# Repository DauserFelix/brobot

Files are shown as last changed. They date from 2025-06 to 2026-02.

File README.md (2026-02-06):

# BroBot - 4-DOF Robot Arm with Cycloidal Gearbox

A DIY 4-axis robot arm driven by stepper motors with cycloidal reduction gears and inverse kinematics control.

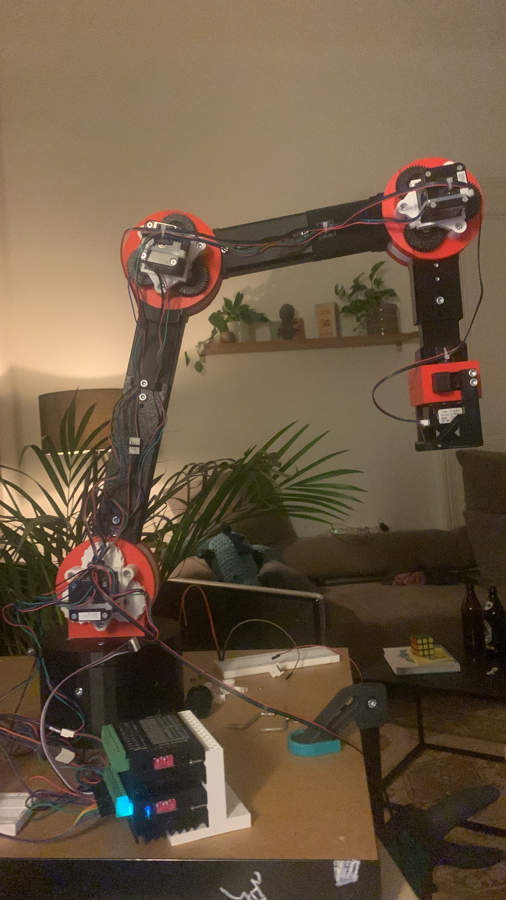
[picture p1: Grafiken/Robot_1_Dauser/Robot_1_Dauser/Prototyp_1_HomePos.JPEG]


BroBot is a DIY robot arm with 4 degrees of freedom (DOF) driven by stepper motors and cycloidal gearboxes. The project includes both the mechanical construction and software control with inverse kinematics for precise TCP positioning (Tool Center Point).

### Specifications

- **Degrees of Freedom:** 4 DOF
- **Base Height to Joint 1:** 150 mm
- **Link Lengths:**
  - L1: 150 mm (Base to Joint 1)
  - L2: 200 mm (Joint 1 to Joint 2)
  - L3: 180 mm (Joint 2 to Joint 3)
  - L4: 120 mm (Joint 3 to TCP)
- **Maximum Reach:** ~500 mm
- **Actuators:** NEMA 17/23 Stepper Motors
- **Gearing:** Cycloidal reduction gears (see exploded view)

## Features

### Hardware
- Cycloidal gearboxes for high reduction ratio and precision
- 3D printed components
- TB6600 stepper motor drivers (up to 4A)
- Arduino-based controller
- Compact design

### Software
- **Inverse Kinematics** - Control via cartesian coordinates (X, Y, Z)
- **Forward Kinematics** - Calculate TCP position from joint angles
- **Python Control Interface** - Command-line interface for easy operation
- **Arduino Firmware** - Real-time stepper motor control
- **Relative & Absolute Movement** - Flexible positioning options
- **Home Position** - Safe reference position

## Hardware

### Components

#### Drive System
- 4x NEMA 17/23 Stepper Motors
- 4x TB6600 Stepper Motor Drivers
- 1x Power Supply 24-36V DC (recommended)
- Arduino Uno/Mega

#### Mechanics
- Cycloidal gearboxes (3D printed)
- Structural parts (3D printed or aluminum)
- Various screws, bearings, and mounting hardware

### TB6600 Stepper Motor Driver

**Specifications:**
- Supply Voltage: 9-40 VDC (optimal: 24-36V)
- Output Current: 0.7-4.0A (adjustable via DIP switches)
- Microstepping Modes: up to 6400 steps/revolution
- Input Signal: 5V (optically isolated)
- Max. Pulse Frequency: 20 kHz

**Connections:**
- **PUL+/PUL-:** Pulse input (Step)
- **DIR+/DIR-:** Direction input
- **ENA+/ENA-:** Enable input
- **A+/A-, B+/B-:** Motor connections

**Important Notes:**
- For 12V control signals: add 1kΩ resistor in series
- For 24V control signals: add 2kΩ resistor in series

### Cycloidal Gearbox

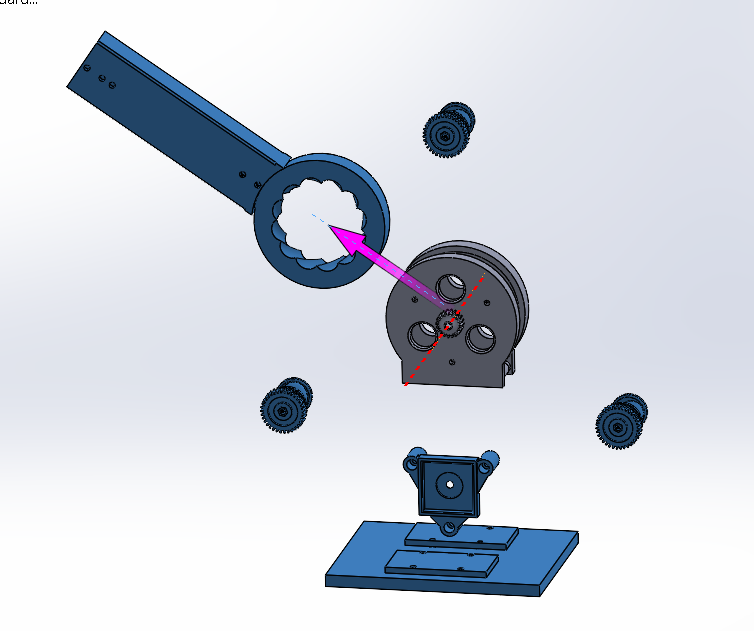
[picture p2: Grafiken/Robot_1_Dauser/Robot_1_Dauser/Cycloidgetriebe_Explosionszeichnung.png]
  

The cycloidal gearbox provides:
- High reduction ratios (typically 1:30 to 1:100)
- Very low backlash
- High stiffness
- Compact form factor
- Self-locking at high reduction ratios

## Software

### Architecture

```
┌─────────────────────────────────────┐
│   Python TCP Control Interface      │
│  (Inverse & Forward Kinematics)     │
└────────────────┬────────────────────┘
                 │ Serial (9600 baud)
                 │ Commands: J1:steps, J2:steps...
┌────────────────▼────────────────────┐
│     Arduino Firmware                │
│  (Stepper Control & Positioning)    │
└────────────────┬────────────────────┘
                 │ Step/Dir Signals
┌────────────────▼────────────────────┐
│      TB6600 Stepper Drivers         │
└────────────────┬────────────────────┘
                 │
┌────────────────▼────────────────────┐
│        Stepper Motors               │
└─────────────────────────────────────┘
```

### Calibration - Steps per Degree

The calibration values are based on measured data from the actual system:

| Joint | Steps/90° | Steps/Degree |
|---|---|---|
| 1 | 5500 | 61.11 |
| 2 | 8000 | 88.89 |
| 3 | 5000 | 55.56 |
| 4 | 5000 | 55.56 |

## Installation

### Prerequisites

- Python 3.7 or higher
- Arduino IDE
- pySerial library

### Python Setup

```bash
# Clone repository
git clone https://github.com/yourusername/brobot.git
cd brobot

# Create virtual environment (optional)
python -m venv venv
source venv/bin/activate  # Linux/Mac
# or
venv\Scripts\activate  # Windows

# Install dependencies
pip install pyserial
```

### Arduino Setup

1. Open Arduino IDE
2. Load `arudino_inverse_kinematics_automatic_ansteuerung_brobot.ino`
3. Select your board (Arduino Uno/Mega)
4. Select the correct COM port
5. Upload to Arduino

### Configuration

In `python_inverse_kinematics_brobot.py`:

```python
# Adjust serial port
arduino_port = 'COM3'  # Windows
# arduino_port = '/dev/ttyUSB0'  # Linux
# arduino_port = '/dev/tty.usbserial-XXX'  # Mac

# Link lengths (if different from default)
L1 = 150  # mm
L2 = 200  # mm
L3 = 180  # mm
L4 = 120  # mm
```

## Usage

### Starting the Control Interface

```bash
python python_inverse_kinematics_brobot.py
```

### Initialization

At startup, you'll be prompted to enter the current joint angles:

```
Please enter current joint angles (in degrees):
  Joint 1: 0
  Joint 2: 45
  Joint 3: 90
  Joint 4: -45
```

### Commands

#### Absolute Positioning
```bash
TCP> goto 300 100 200
# Moves TCP to position X=300mm, Y=100mm, Z=200mm
```

#### Relative Movement
```bash
TCP> up 10        # Move 10mm upward
TCP> down 5       # Move 5mm downward
TCP> forward 20   # Move 20mm forward
TCP> back 15      # Move 15mm backward
TCP> left 10      # Move 10mm to the left
TCP> right 10     # Move 10mm to the right
```

#### Other Commands
```bash
TCP> status       # Show current position and angles
TCP> home         # Move to home position
TCP> stop         # Stop all movements
TCP> help         # Show all commands
TCP> exit         # Exit program
```

### Example Session

```bash
TCP> goto 400 0 150
Moving TCP to position: X=400.0, Y=0.0, Z=150.0
Calculated joint angles:
  Joint 1: 0.0°
  Joint 2: 45.2°
  Joint 3: 67.8°
  Joint 4: -23.0°
→ Joint 1: 0.0° (0 Steps)
→ Joint 2: 45.2° (4018 Steps)
→ Joint 3: 67.8° (3767 Steps)
→ Joint 4: -23.0° (-1278 Steps)

TCP> up 50
[...]

TCP> status
============================================================
ROBOT STATUS
============================================================
TCP Position: X=400.0, Y=0.0, Z=200.0 mm

Joint Angles:
  Joint 1: 0.0°
  Joint 2: 52.3°
  Joint 3: 71.2°
  Joint 4: -33.5°
============================================================
```

## Kinematics

### Inverse Kinematics

The inverse kinematics algorithm calculates the required joint angles for a desired TCP position:

**Coordinate System:**
- X: Forward/Backward
- Y: Left/Right
- Z: Up/Down

**Solution Approach:**
1. Joint 1 (Base): `θ₁ = atan2(y, x)`
2. Reduce to 2D problem in the XZ plane
3. Calculate Joint 2 & 3 using the law of cosines
4. Joint 4: Compensate to keep end-effector horizontal

**Workspace Limits:**
- Maximum reach: L2 + L3 + L4 = 500 mm
- Minimum reach: |L2 - L3 - L4| (depends on configuration)

### Forward Kinematics

Calculates the TCP position from given joint angles:

```
x_tcp = (L2·cos(θ₂) + L3·cos(θ₂+θ₃) + L4·cos(θ₂+θ₃+θ₄)) · cos(θ₁)
y_tcp = (L2·cos(θ₂) + L3·cos(θ₂+θ₃) + L4·cos(θ₂+θ₃+θ₄)) · sin(θ₁)
z_tcp = L1 + L2·sin(θ₂) + L3·sin(θ₂+θ₃) + L4·sin(θ₂+θ₃+θ₄)
```

### Working Position
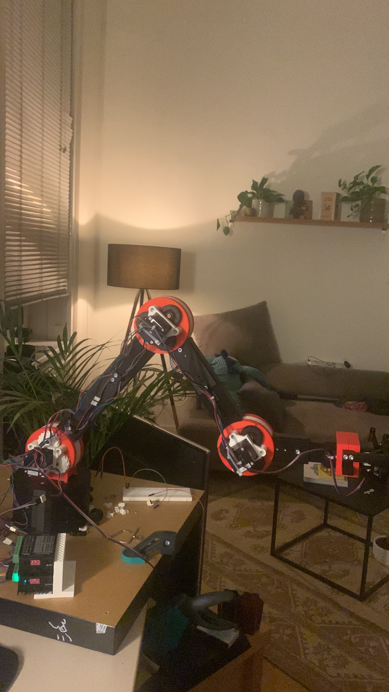
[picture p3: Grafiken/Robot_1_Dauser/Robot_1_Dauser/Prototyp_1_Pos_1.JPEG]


## End-Effector: Parallel Gripper with Toggle Mechanism

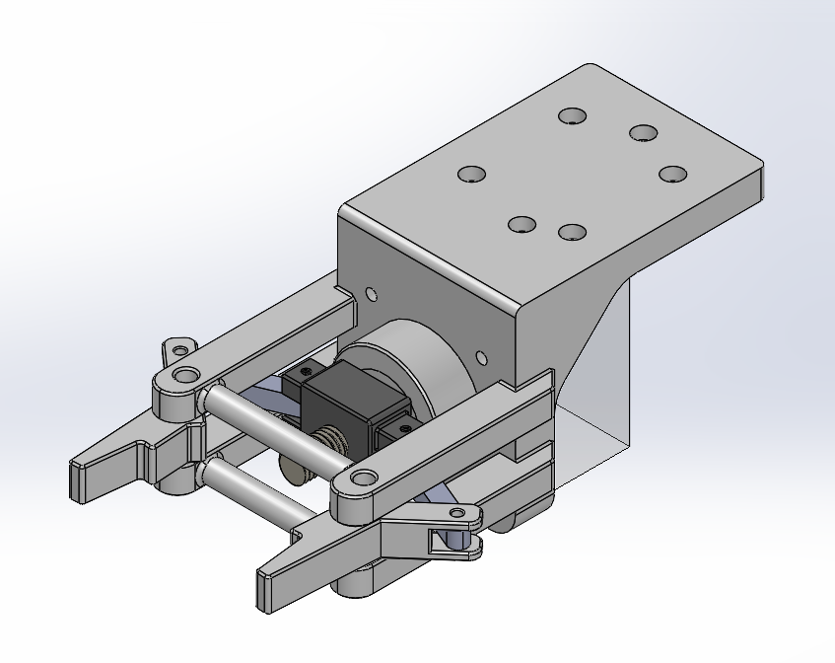
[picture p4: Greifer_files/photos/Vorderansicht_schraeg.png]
Gripper Perspective


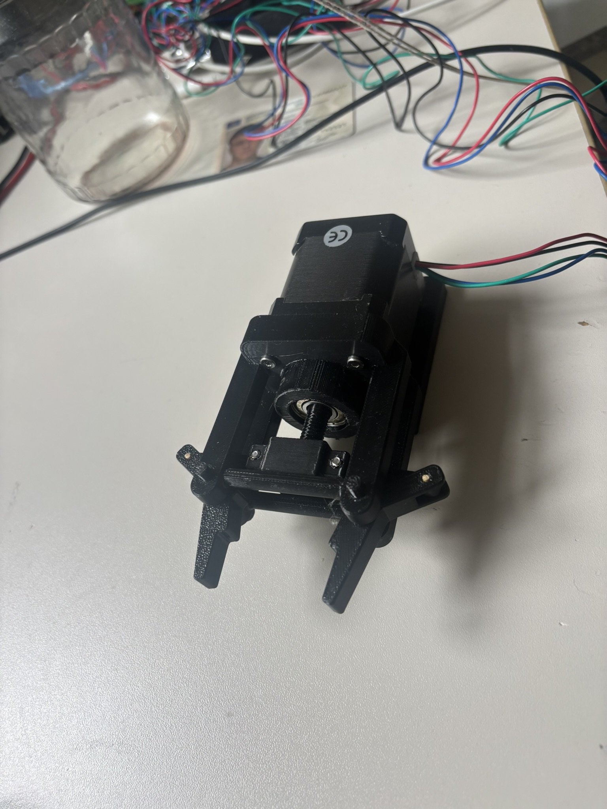
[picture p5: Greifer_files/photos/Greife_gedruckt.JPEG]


A motorized parallel gripper designed as an end-effector for the BroBot. The gripper uses a NEMA 17 stepper motor driven by the same TB6600 drivers as the robot joints.
Key Features

### Toggle Mechanism: Employs a knee-lever mechanism for mechanical advantage, dramatically amplifying gripping force as the jaws close
Same Hardware: Uses NEMA 17 motor and TB6600 driver (compatible with existing BroBot electronics)
Parallel Jaws: Ensures even pressure distribution across gripping surfaces
Compact Design: Lightweight and suitable for mounting on Joint 4/TCP

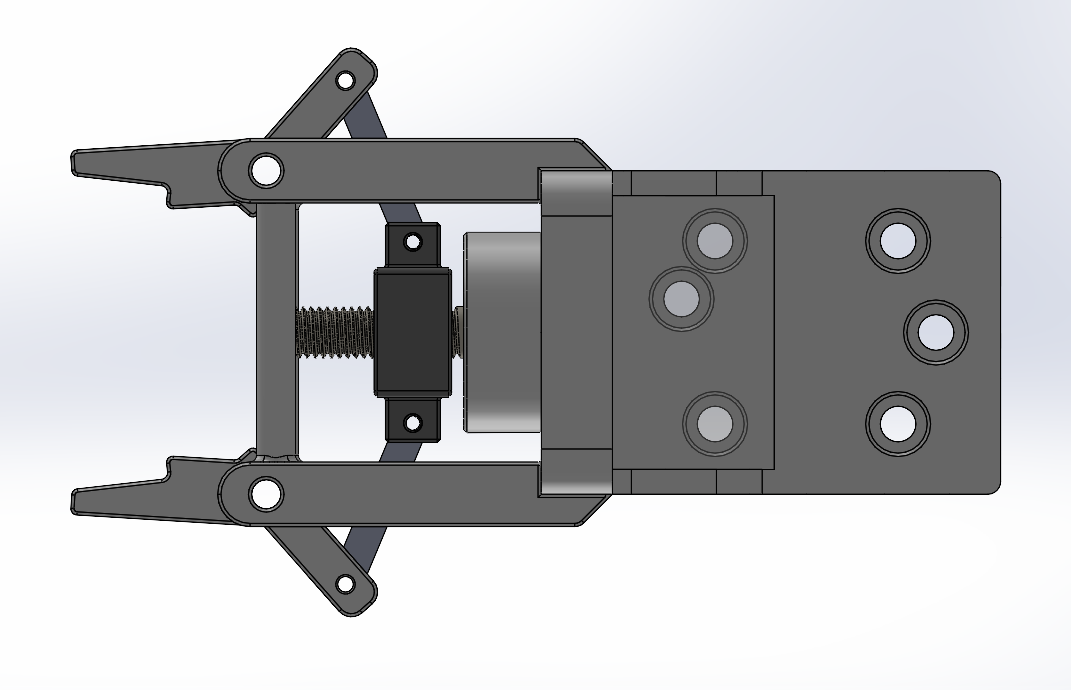
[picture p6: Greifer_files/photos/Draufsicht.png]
Gripper Top View


### Toggle Mechanism Principle
The gripper uses a toggle (knee-lever) mechanism that provides increasing mechanical advantage as the jaws approach the closed position. This allows high clamping forces with minimal motor torque and enables the gripper to maintain grip even when not actively powered.
Integration
The gripper connects mechanically to the BroBot's TCP and electrically to an additional TB6600 driver. Control is integrated into the existing Arduino/Python interface as an additional "Joint 5" for simple open/close commands.

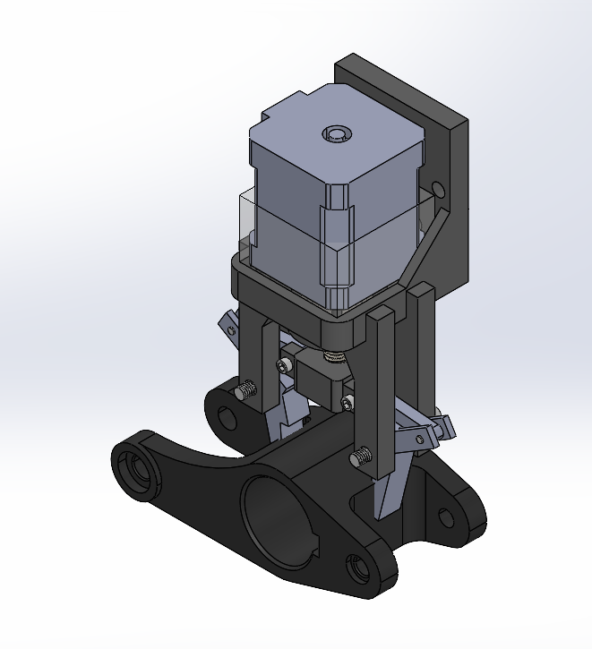
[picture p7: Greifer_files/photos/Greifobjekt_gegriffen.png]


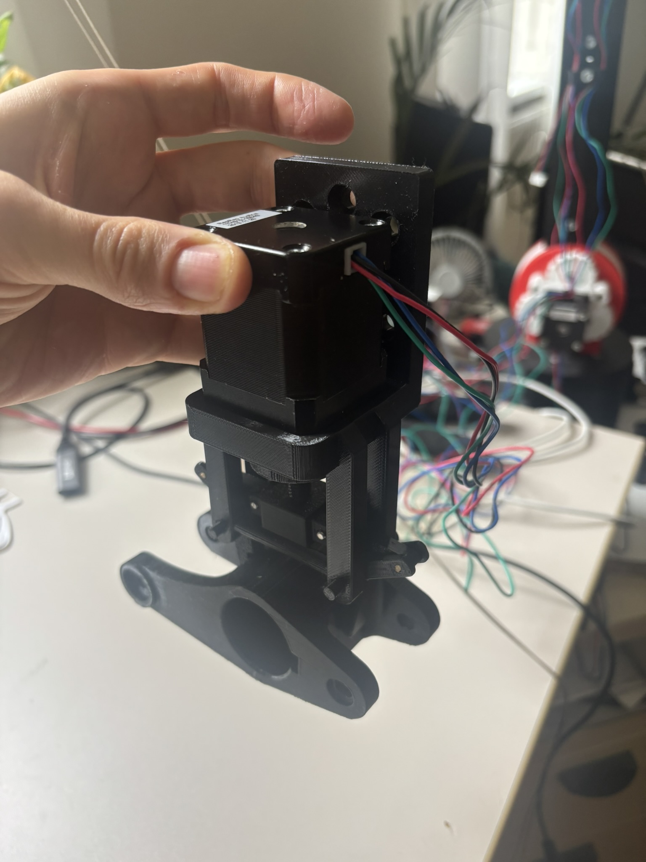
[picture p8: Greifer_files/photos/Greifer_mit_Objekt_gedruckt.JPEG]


### Components
1x NEMA 17 Stepper Motor
1x TB6600 Driver
3D printed gripper jaws and toggle linkages
Various bearings and fasteners

## Troubleshooting

### Common Issues

**Issue: "Position not reachable!"**
- Solution: Check if the target position is within the workspace
- Maximum reach: ~500mm from origin

**Issue: Motors not moving**
- Check wiring to TB6600 drivers
- Check power supply (minimum 9V)
- Check enable signal
- Verify DIP switch settings on TB6600

**Issue: Steps are being lost**
- Reduce speed (increase delay in Arduino code)
- Check current setting on TB6600
- Check for mechanical friction or binding

**Issue: Serial connection fails**
- Verify COM port in `python_inverse_kinematics_brobot.py`
- Check if Arduino is connected
- Close Arduino IDE Serial Monitor if open

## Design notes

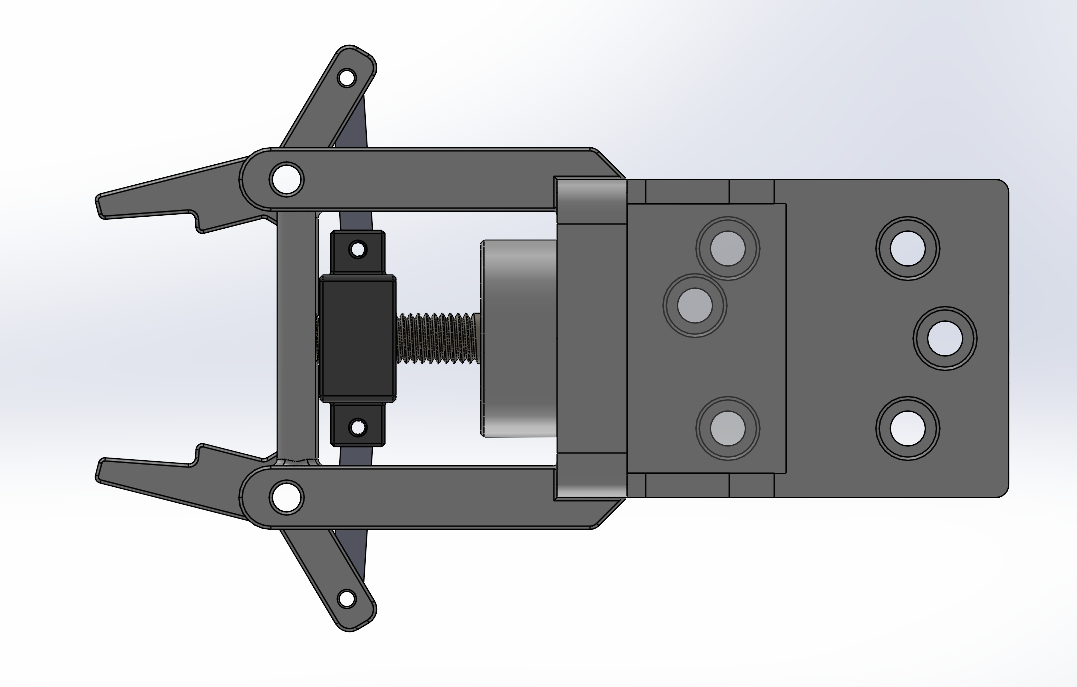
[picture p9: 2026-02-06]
Greifer_files/photos/Draufsicht_Greifer_geschlossen.png

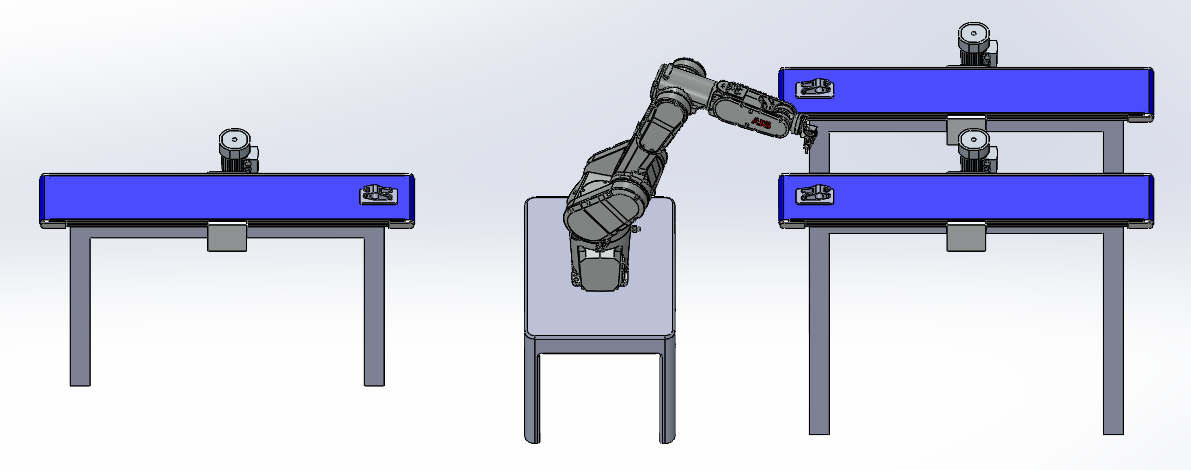
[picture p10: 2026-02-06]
Greifer_files/photos/Station_Seitenansicht_schraeg.png

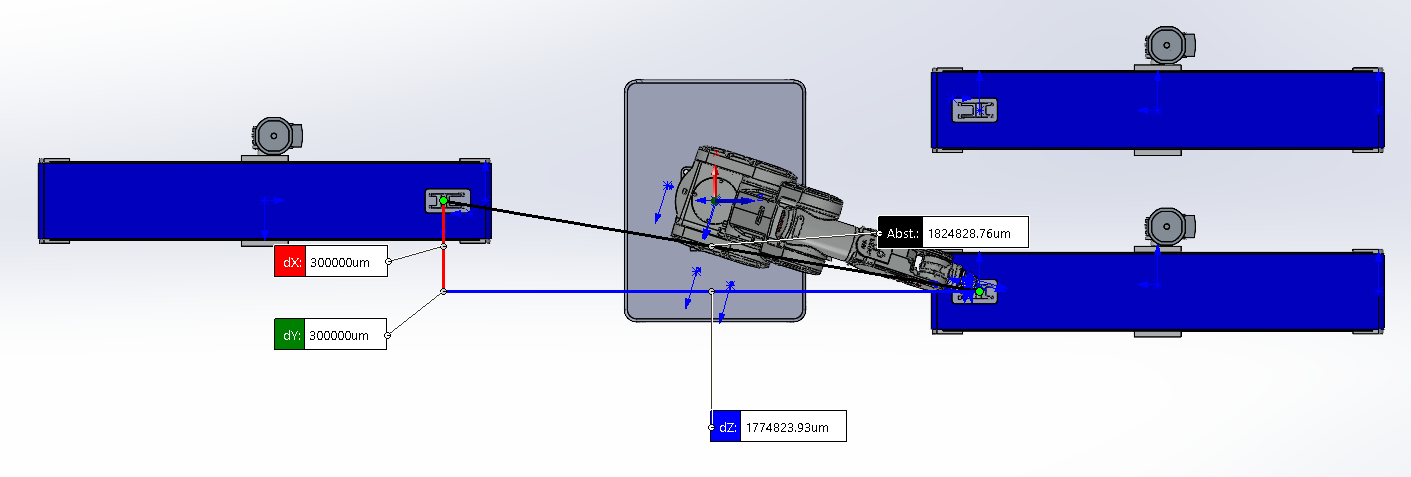
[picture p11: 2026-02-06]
Greifer_files/photos/Abstand_Aufnahme_und_Ablage_Draufsicht.png

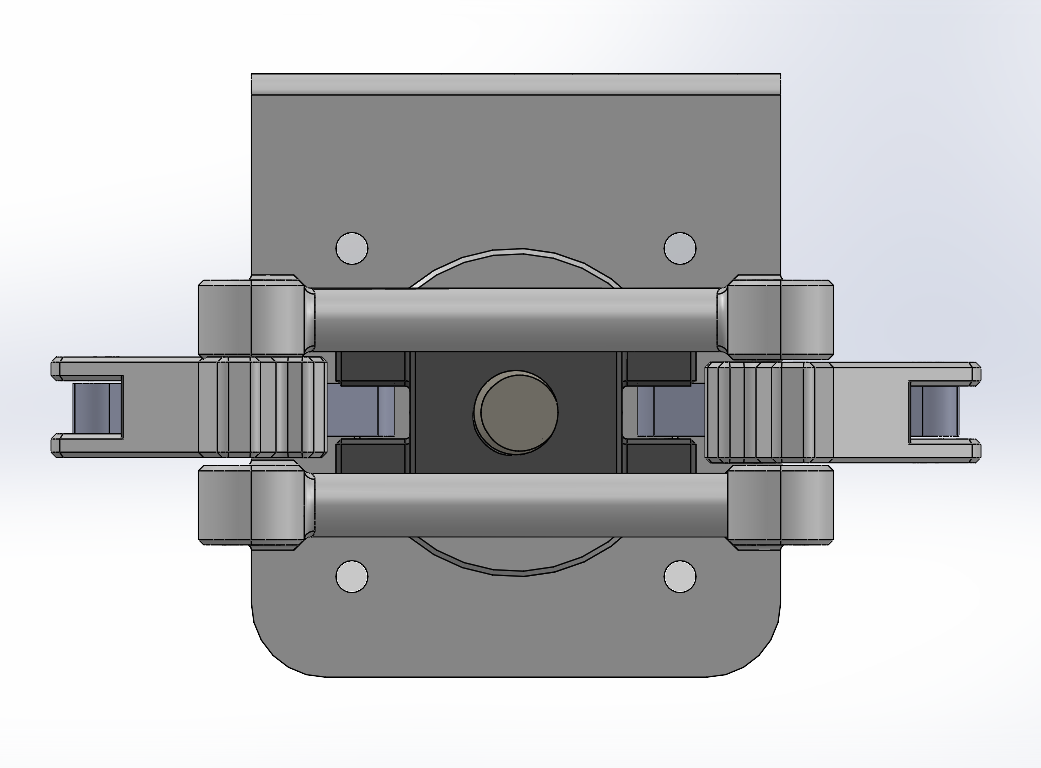
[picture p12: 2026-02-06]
Greifer_files/photos/Vorderansicht.png

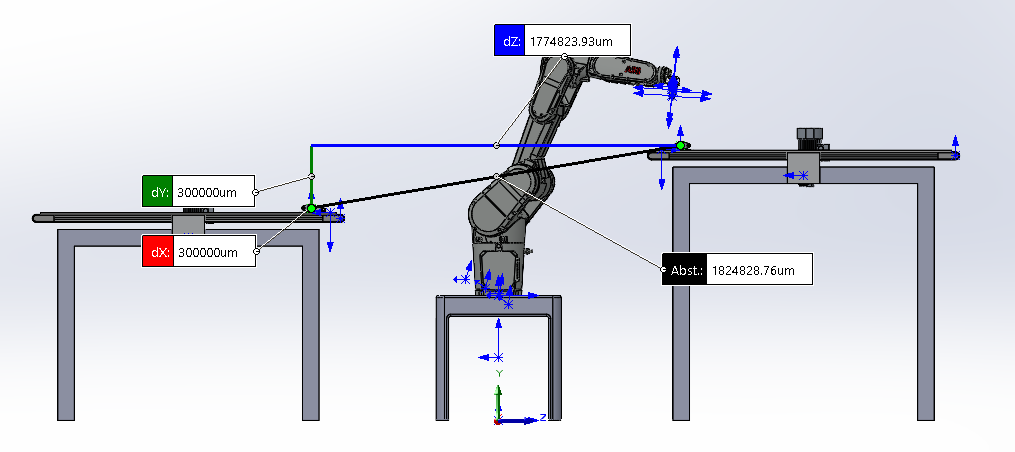
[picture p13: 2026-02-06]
Greifer_files/photos/Abstand_Aufnahme_und_Ablage_Seitenansicht.png

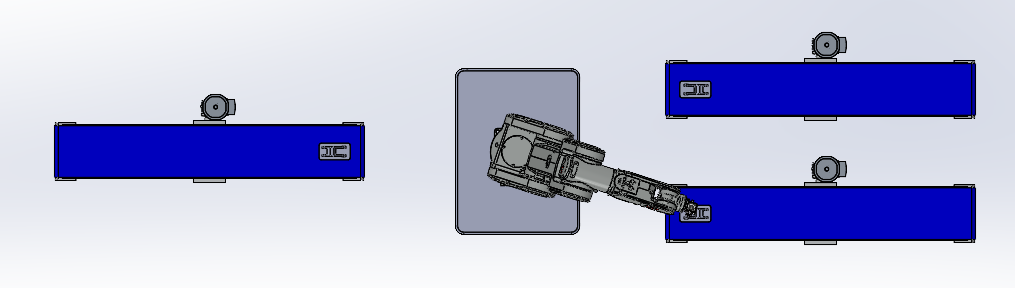
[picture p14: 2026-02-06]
Greifer_files/photos/Stattion_Draufsicht.png

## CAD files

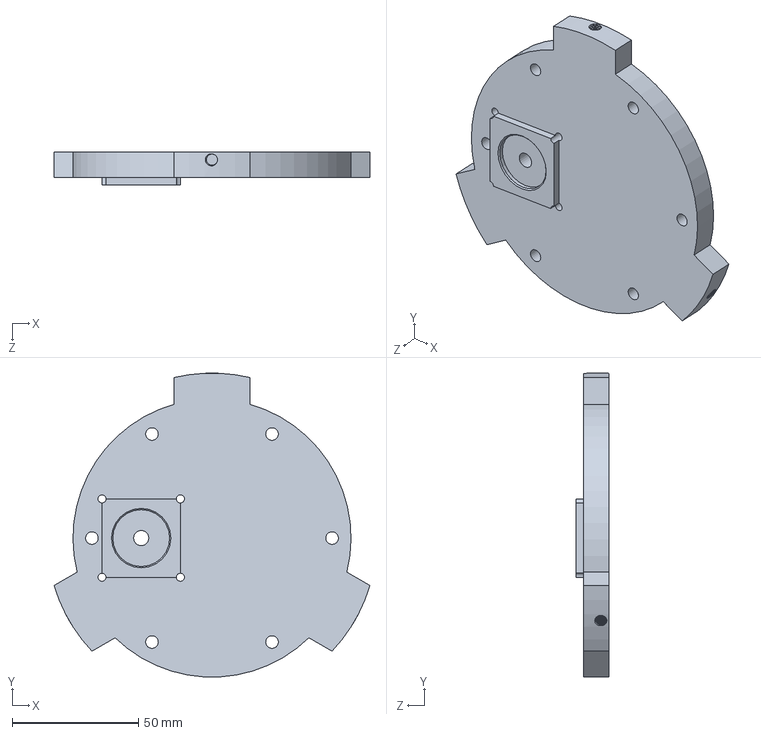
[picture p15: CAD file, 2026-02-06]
CAD/base/Base-Rotationsgelenk_4_v1.SLDPRT
125.0 x 120.2 x 13.0 mm

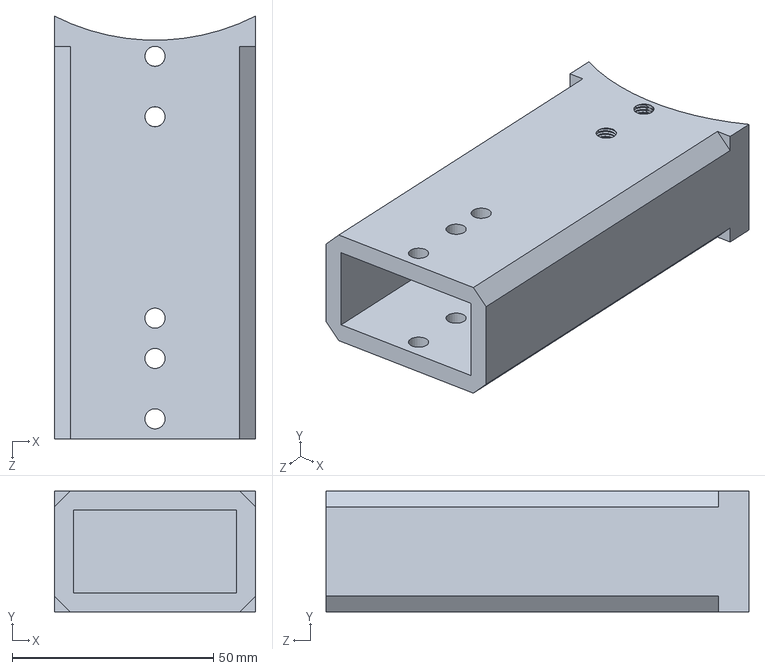
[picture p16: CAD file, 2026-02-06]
CAD/cycloid_innenkaefig/ausleger_3_100mm.SLDPRT
50.0 x 30.0 x 105.0 mm

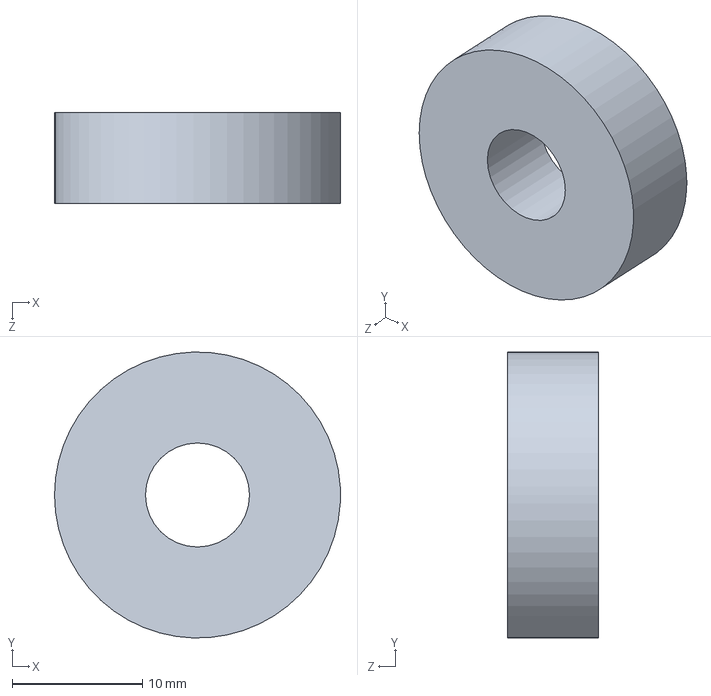
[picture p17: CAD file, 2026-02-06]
CAD/cycloid_innenkaefig/Joint_2_V3/Kugellager_22mm_8mm_7mm.SLDPRT
22.0 x 22.0 x 7.00 mm

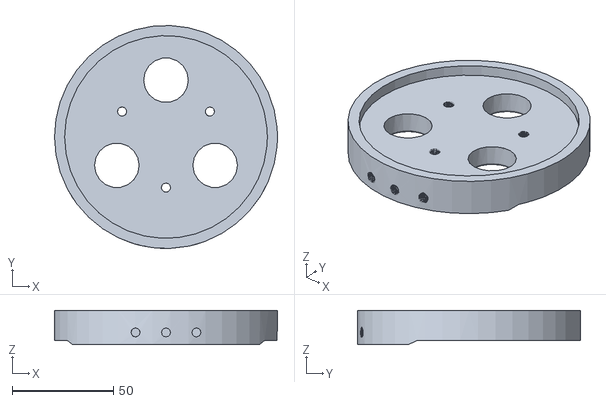
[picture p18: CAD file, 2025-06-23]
CAD/cycloid_innenkaefig/Joint_4/frame_3_v2_3_verstrebungen.STL
110.0 x 110.0 x 16.9

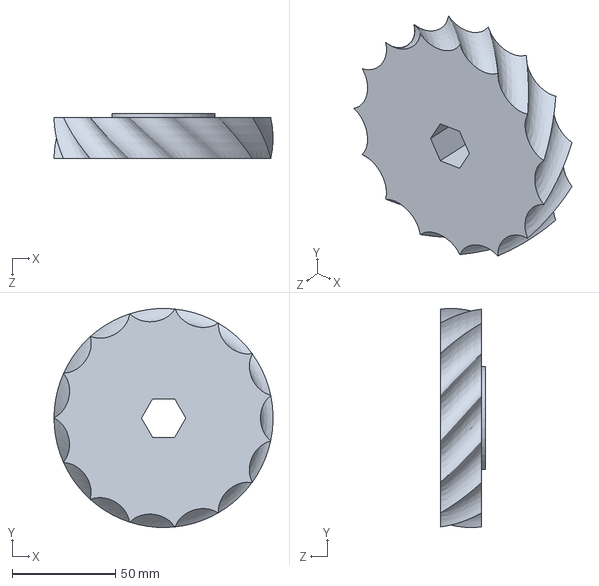
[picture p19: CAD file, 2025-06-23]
CAD/cycloid_innenkaefig/Voruebersetzung_cycloid_außen/Cycloidal_wheel.SLDPRT
106.1 x 106.1 x 22.0 mm

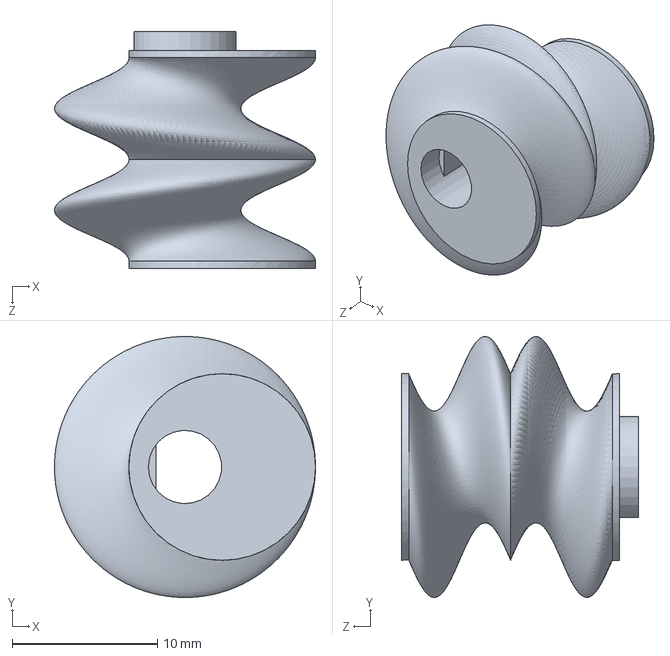
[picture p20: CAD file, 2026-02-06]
CAD/cycloid_innenkaefig/Voruebersetzung_cycloid_außen/V2.2/cycloid_welle.SLDPRT
18.0 x 18.0 x 16.3 mm

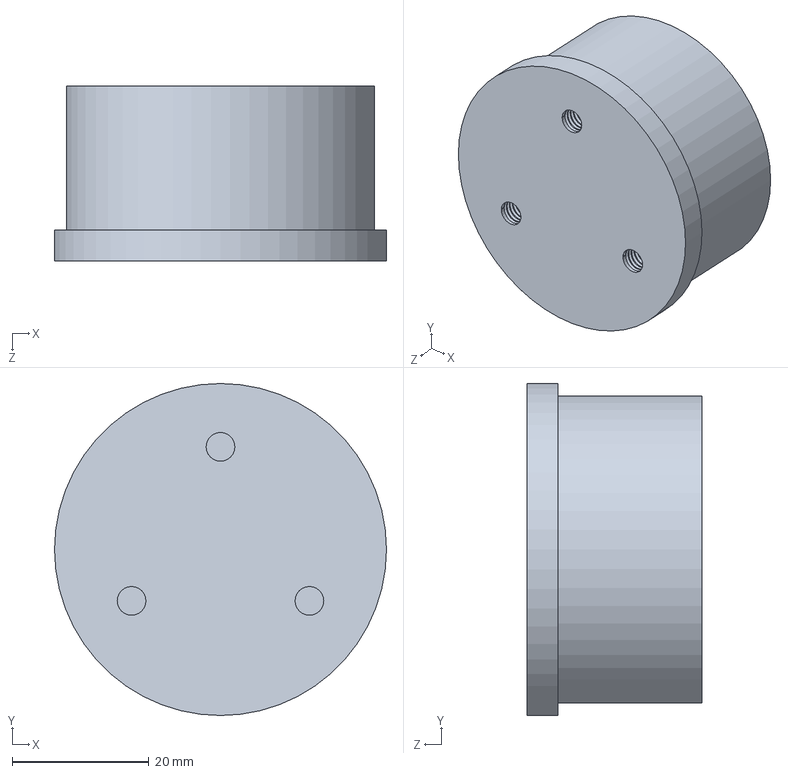
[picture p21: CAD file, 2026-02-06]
CAD/nylongetriebe/Version_1/Mittelachse.SLDPRT
48.5 x 48.5 x 25.5 mm

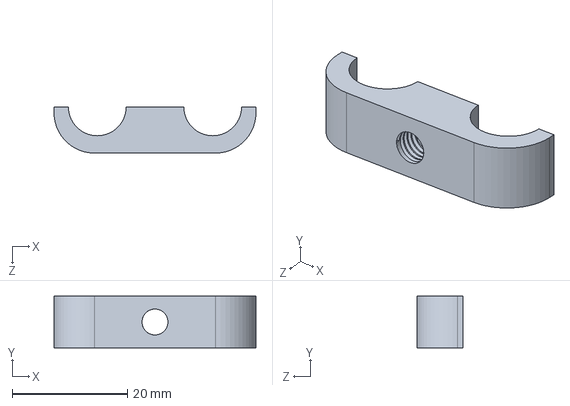
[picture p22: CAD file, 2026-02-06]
CAD/sonstiges/Kabelhalterung.SLDPRT
35.0 x 9.00 x 8.00 mm

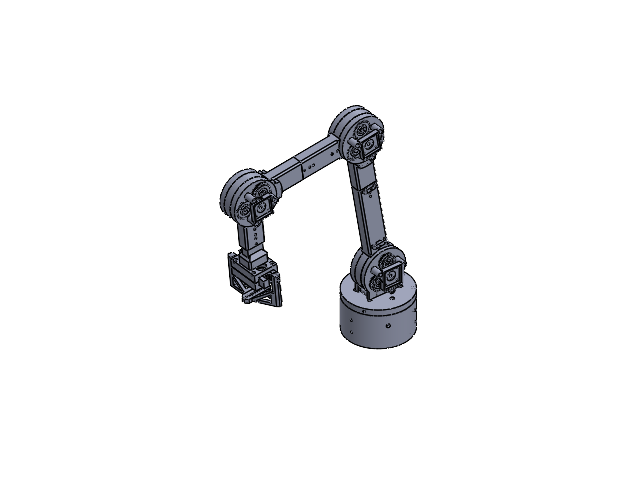
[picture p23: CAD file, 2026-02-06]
CAD/brobot.SLDASM
Base-Rotationsgelenk_3_v1
Base-Rotationsgelenk_2_v1
Base-Rotationsgelenk_1_v1
Base-Rotationsgelenk_4_v1
Cycloidal_pin_fuer_Base
Cycloidal_cage x 3
Teil4^Fully_cage
Cycloidal_pin_mit_fuehrung x 3
frame_2
frame_3
Zahnrad_1 x 3
Zahnrad_2_NEMA17
halterung_NEMA17 x 3
ausleger_1
frame_2_v2_3_Verstrebungen x 2
frame_3_v2_3_verstrebungen x 2
Cycloidal_pin_mit_fuehrung_und_Gewinde x 6
cycloid_rad x 6
cycloid_welle x 2
Kabelhalterung x 2
ausleger_3_100mm
ausleger_2_80mm x 2
frame_1_endeffektor
Linearführung_endeffektor_ x 2
Zahnrad_endeffektor
Zahnrad_endeffektor_fuehrung x 2
frame_2_endeffektor
gripper_1 x 2
ausleger_endeffektor
ausleger_endeffektor_verbindungselement
Greiferbacken x 2

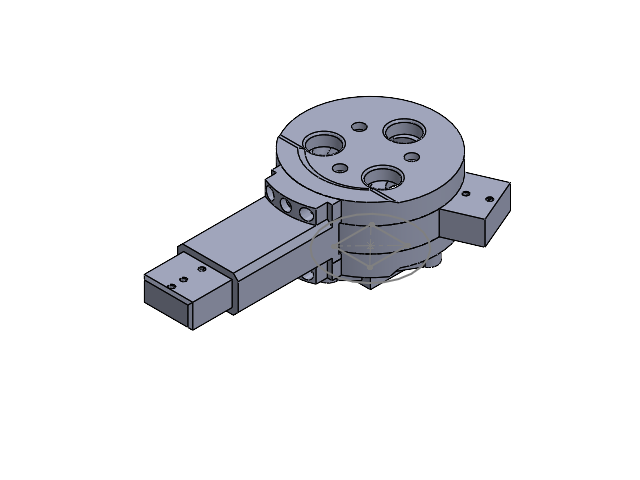
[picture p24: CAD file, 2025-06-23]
CAD/cycloid_innenkaefig/Joint_4/Joint_4.SLDASM
ausleger_2_80mm
frame_2_v2_3_Verstrebungen
frame_3_v2_3_verstrebungen
Cycloidal_cage
halterung_NEMA17

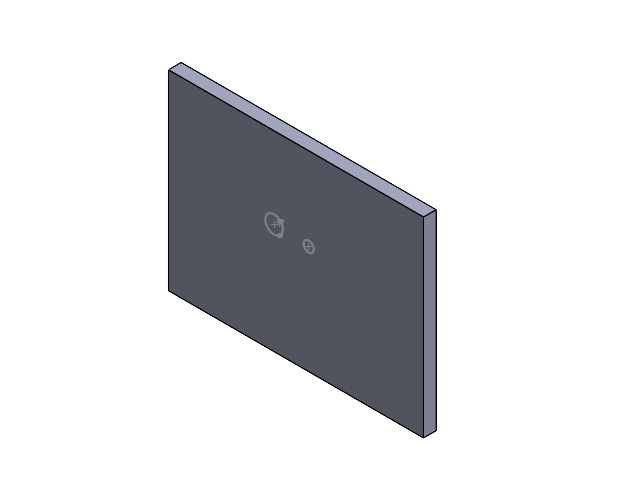
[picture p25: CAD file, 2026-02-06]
CAD/cycloid_innenkaefig/Voruebersetzung_cycloid_außen/V2.2/Cycloidgetriebe_own.SLDASM
Halterung_provisorisch
cycloid_rad
cycloid_welle

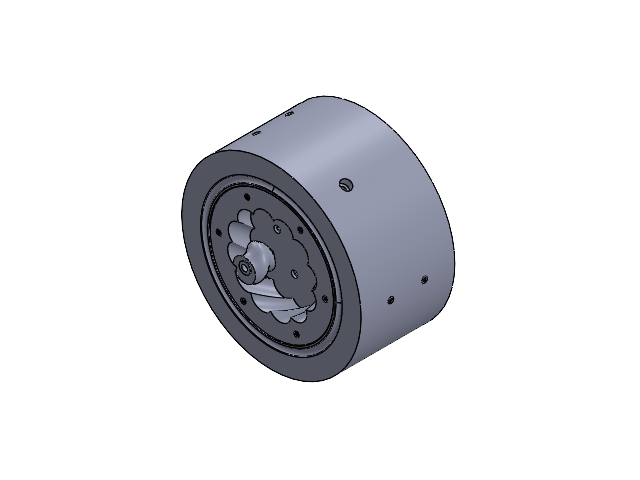
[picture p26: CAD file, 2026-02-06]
CAD/base/base.SLDASM
Base-Rotationsgelenk_2_v1
Base-Rotationsgelenk_1_v1
Base-Rotationsgelenk_4_v1
Cycloidal_pin_fuer_Base

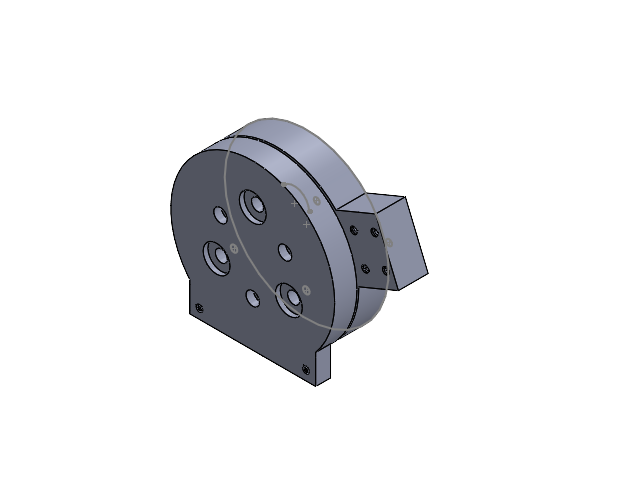
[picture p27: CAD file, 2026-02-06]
CAD/cycloid_innenkaefig/Joint_2_V3/Cycloidal_Joint_2.SLDASM
Kugellager_22mm_8mm_7mm x 5
Cycloidal_pin_mit_fuehrung_und_Gewinde x 2
frame_3
Cycloidal_cage

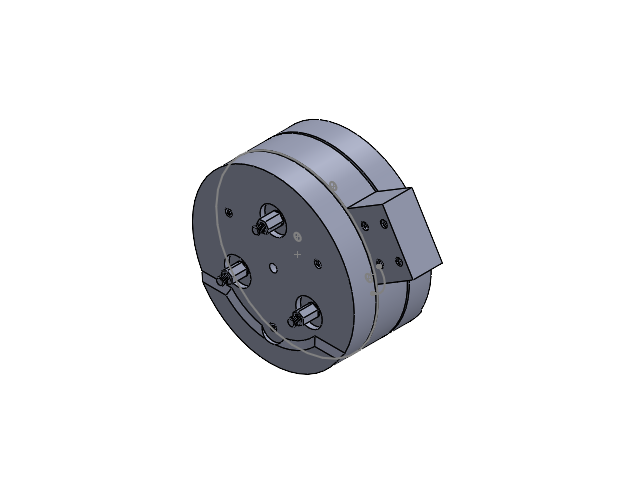
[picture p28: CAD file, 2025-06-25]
CAD/cycloid_innenkaefig/Joint_2_V3/Cycloidal_round.SLDASM
frame_3_v2_3_verstrebungen
Cycloidal_cage
Cycloidal_pin_mit_fuehrung_und_Gewinde x 3
frame_2_v2_3_Verstrebungen
Kugellager_22mm_8mm_7mm x 6

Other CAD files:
CAD/nylongetriebe/Version_1/System_1.SLDASM
CAD/cycloid_innenkaefig/Fully_cage_round.SLDASM
CAD/cycloid_innenkaefig/Fully_cage.SLDASM
CAD/cycloid_planetengetriebe/plaenen_cage.SLDPRT
CAD/base/Base-Rotationsgelenk_3_v1.STL
CAD/base/Base-Rotationsgelenk_4_v1.STL
CAD/base/Base-Rotationsgelenk_5_Sockel_v1.SLDPRT
CAD/base/Cycloidal_pin.SLDPRT
CAD/base/Cycloidal_pin_fuer_Base.SLDPRT
CAD/base/Cycloidal_pin_fuer_Base.STL
CAD/cycloid_innenkaefig/Cycloidal_cage.SLDPRT
CAD/cycloid_innenkaefig/Cycloidal_cage.STEP
CAD/cycloid_innenkaefig/Cycloidal_cage.STL
CAD/cycloid_innenkaefig/Cycloidal_pin.SLDPRT
CAD/cycloid_innenkaefig/Cycloidal_pin.STEP
CAD/cycloid_innenkaefig/Cycloidal_pin.STL
CAD/cycloid_innenkaefig/Cycloidal_pin_mit_fuehrung.SLDPRT
CAD/cycloid_innenkaefig/Cycloidal_pin_mit_fuehrung.STL
CAD/cycloid_innenkaefig/Cycloidal_pin_mit_fuehrung_und_Gewinde.SLDPRT
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

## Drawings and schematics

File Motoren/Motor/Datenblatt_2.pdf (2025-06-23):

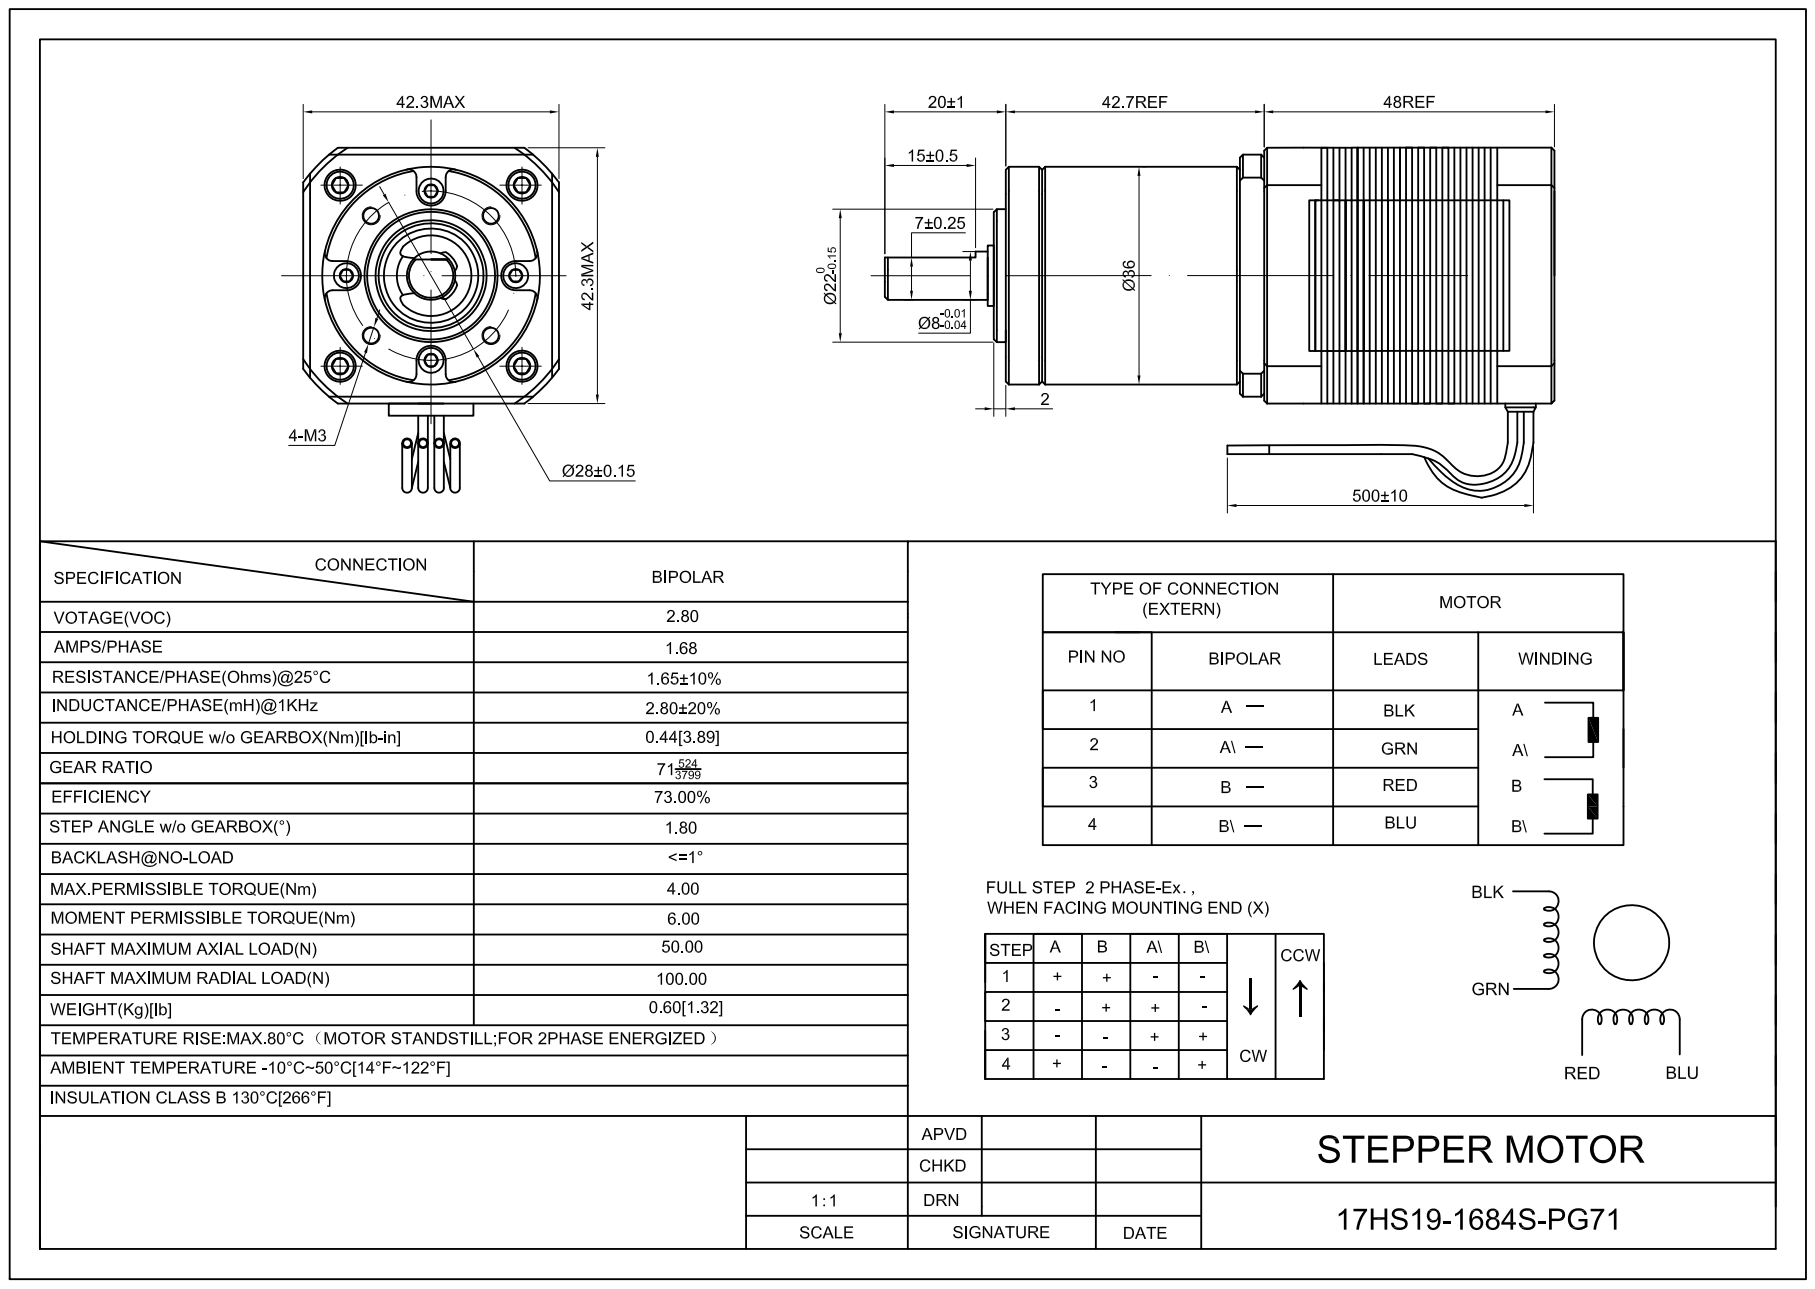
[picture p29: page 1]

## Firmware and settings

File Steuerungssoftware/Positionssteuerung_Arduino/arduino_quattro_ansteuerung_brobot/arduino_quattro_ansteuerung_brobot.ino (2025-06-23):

// TB6600 Schrittmotor-Treiber - Multi Joint Version (4 Joints)
const int JOINT1_PINS[3] = {8, 9, 10};   // STEP, DIR, ENA für Joint 1
const int JOINT2_PINS[3] = {11, 12, 13}; // STEP, DIR, ENA für Joint 2
const int JOINT3_PINS[3] = {5, 6, 7};    // STEP, DIR, ENA für Joint 3
const int JOINT4_PINS[3] = {2, 3, 4};    // STEP, DIR, ENA für Joint 4

// Aktuelle Pin-Variablen (werden je nach ausgewähltem Joint gesetzt)
int STEP_PIN = 8;
int DIR_PIN = 9;
int ENA_PIN = 10;

// Konfigurierbare Parameter
double pulseDelay = 400;     // Verzögerung zwischen Schritten in Mikrosekunden
boolean motorDirection = LOW;  // Drehrichtung (LOW oder HIGH)
boolean motorEnabled = true;   // Motor aktiviert (true) oder deaktiviert (false)
String receivedCommand = "";   // Empfangener Befehl
boolean commandComplete = false;

unsigned long lastStepTime = 0;
bool stepState = LOW;

// Fehlercodes - synchronisiert mit Python
const String CODE1 = "Code1: Position wurde angefahren";
const String CODE2 = "Code2: Vorgang wurde abgebrochen";
const String CODE3 = "Code3: Motor ist einsatzbereit!";
const String CODE4 = "Code4: Fehlerhafte Eingabe. Motor wurde abgeschaltet";

// Joint-Bestätigungscodes
const String JOINT1_CODE = "Arduino: Joint 1 wird angesteuert";
const String JOINT2_CODE = "Arduino: Joint 2 wird angesteuert";
const String JOINT3_CODE = "Arduino: Joint 3 wird angesteuert";
const String JOINT4_CODE = "Arduino: Joint 4 wird angesteuert";

// Positionsvariablen
long targetPosition = 0;
long currentPosition = 0;
boolean movingToPosition = false;

// Aktuell aktiver Joint
int currentJoint = 1;

// Debug-Variablen
unsigned long lastDebug = 0;
unsigned long stepCount = 0;

// Geschwindigkeitsstufen (1-5)
const double speedLevels[6] = {0, 1000, 600, 400, 200, 100}; // Index 0 unbenutzt, 1-5 für Stufen

void setup() {
  // Pin-Modi für alle vier Joints setzen
  for(int i = 0; i < 3; i++) {
    pinMode(JOINT1_PINS[i], OUTPUT);
    pinMode(JOINT2_PINS[i], OUTPUT);
    pinMode(JOINT3_PINS[i], OUTPUT);
    pinMode(JOINT4_PINS[i], OUTPUT);
  }
  
  // Serielle Kommunikation starten
  Serial.begin(9600);
  
  // Standardmäßig Joint 1 aktivieren
  setActiveJoint(1);
  
  // Anfangszustand setzen
  digitalWrite(DIR_PIN, motorDirection);
  digitalWrite(ENA_PIN, motorEnabled ? LOW : HIGH);  // LOW = aktiviert, HIGH = deaktiviert
  
  // Bereitschaftsmeldung
  Serial.println(CODE3);
  Serial.println("DEBUG: Setup abgeschlossen - Joint 1 aktiv");
  printStatus();
}

void loop() {
  // Auf serielle Befehle prüfen
  if (Serial.available() > 0) {
    char inChar = (char)Serial.read();
    
    // Spezielle Joint-Auswahl Befehle (als Byte-Werte)
    if (inChar == 1) {
      setActiveJoint(1);
      Serial.println(JOINT1_CODE);
      return;
    }
    else if (inChar == 2) {
      setActiveJoint(2);
      Serial.println(JOINT2_CODE);
      return;
    }
    else if (inChar == 3) {
      setActiveJoint(3);
      Serial.println(JOINT3_CODE);
      return;
    }
    else if (inChar == 4) {
      setActiveJoint(4);
      Serial.println(JOINT4_CODE);
      return;
    }
    
    // Normale String-Befehle verarbeiten
    if (inChar == '\n' || inChar == '\r') {
      if (receivedCommand.length() > 0) {
        commandComplete = true;
      }
    } else {
      receivedCommand += inChar;
    }
  }
  
  // Befehl verarbeiten
  if (commandComplete) {
    processCommand(receivedCommand);
    receivedCommand = "";
    commandComplete = false;
  }
  
  // Motor bewegen, wenn Zielposition gesetzt
  if (movingToPosition && motorEnabled) {
    moveToPosition();
  }
}

void setActiveJoint(int jointNumber) {
  currentJoint = jointNumber;
  
  if (jointNumber == 1) {
    STEP_PIN = JOINT1_PINS[0];
    DIR_PIN = JOINT1_PINS[1];
    ENA_PIN = JOINT1_PINS[2];
  } else if (jointNumber == 2) {
    STEP_PIN = JOINT2_PINS[0];
    DIR_PIN = JOINT2_PINS[1];
    ENA_PIN = JOINT2_PINS[2];
  } else if (jointNumber == 3) {
    STEP_PIN = JOINT3_PINS[0];
    DIR_PIN = JOINT3_PINS[1];
    ENA_PIN = JOINT3_PINS[2];
  } else if (jointNumber == 4) {
    STEP_PIN = JOINT4_PINS[0];
    DIR_PIN = JOINT4_PINS[1];
    ENA_PIN = JOINT4_PINS[2];
  }
  
  // Bewegung stoppen beim Joint-Wechsel
  movingToPosition = false;
  currentPosition = 0;
  targetPosition = 0;
  
  // Motor-Zustand für neuen Joint setzen
  digitalWrite(DIR_PIN, motorDirection);
  digitalWrite(ENA_PIN, motorEnabled ? LOW : HIGH);
  
  Serial.print("DEBUG: Joint ");
  Serial.print(jointNumber);
  Serial.println(" ist jetzt aktiv");
}

void printStatus() {
  Serial.println("=== STATUS ===");
  Serial.print("Aktiver Joint: ");
  Serial.print(currentJoint);
  Serial.print(" | Position: ");
  Serial.print(currentPosition);
  Serial.print(" | Ziel: ");
  Serial.print(targetPosition);
  Serial.print(" | Bewegung: ");
  Serial.print(movingToPosition ? "JA" : "NEIN");
  Serial.print(" | Motor: ");
  Serial.print(motorEnabled ? "EIN" : "AUS");
  Serial.print(" | Delay: ");
  Serial.print(pulseDelay);
  Serial.print("µs | Steps: ");
  Serial.println(stepCount);
  Serial.println("==============");
}

void processCommand(String command) {
  command.trim();
  
  Serial.print("DEBUG: Befehl empfangen: '");
  Serial.print(command);
  Serial.println("'");
  
  if (command.equalsIgnoreCase("Stop")) {
    Serial.println("DEBUG: Stop-Befehl");
    movingToPosition = false;
    targetPosition = currentPosition;
    Serial.println(CODE2);
  }
  else if (command.equalsIgnoreCase("Go")) {
    Serial.println("DEBUG: Go-Befehl");
    motorEnabled = true;
    digitalWrite(ENA_PIN, LOW);
    Serial.println(CODE3);
  }
  else if (command == "test") {
    Serial.println("DEBUG: Test-Bewegung gestartet");
    targetPosition = currentPosition + 200;  // 200 Steps vorwärts
    movingToPosition = true;
    motorDirection = HIGH;
    digitalWrite(DIR_PIN, motorDirection);
    Serial.println("Test durchgeführt!"); // Bestätigung
  }
  // Geschwindigkeitsstufen s1-s5
  else if (command == "s1" || command == "s2" || command == "s3" || command == "s4" || command == "s5") {
    int speedLevel = command.substring(1).toInt(); // "s1" -> 1
    pulseDelay = speedLevels[speedLevel];
    Serial.print("Geschwindigkeitsstufe ");
    Serial.print(speedLevel);
    Serial.print(" gesetzt (");
    Serial.print(pulseDelay);
    Serial.println("µs)");
  }
  else if (command.equalsIgnoreCase("d")) {
    Serial.println("DEBUG: Richtungswechsel");
    motorDirection = !motorDirection;  // Richtung umkehren
    digitalWrite(DIR_PIN, motorDirection);
    Serial.println("Richtung geändert"); // Bestätigung
  }
  else if (command.equalsIgnoreCase("e")) {
    Serial.println("DEBUG: Motor ein/aus");
    motorEnabled = !motorEnabled;
    digitalWrite(ENA_PIN, motorEnabled ? LOW : HIGH);  // LOW = aktiviert
    Serial.println("Motor " + String(motorEnabled ? "EIN" : "AUS")); // Bestätigung
  }
  else if (command.equals("+")) {
    Serial.println("DEBUG: Geschwindigkeit erhöhen");
    pulseDelay = max(pulseDelay - 200, 100);  // Mindestverzögerung 100µs
    Serial.print("Geschwindigkeit erhöht auf ");
    Serial.print(pulseDelay);
    Serial.println("µs");
  }
  else if (command.equals("-")) {
    Serial.println("DEBUG: Geschwindigkeit verringern");
    pulseDelay += 200;  // Verzögerung erhöhen
    Serial.print("Geschwindigkeit verringert auf ");
    Serial.print(pulseDelay);
    Serial.println("µs");
  }
  else if (command.equalsIgnoreCase("status")) {
    printStatus();
  }
  else if (command.equalsIgnoreCase("h")) {
    Serial.println("=== HILFE ===");
    Serial.println("s1-s5: Geschwindigkeitsstufen");
    Serial.println("d: Richtung wechseln");
    Serial.println("e: Motor ein/aus");
    Serial.println("+: Geschwindigkeit erhöhen");
    Serial.println("-: Geschwindigkeit verringern");
    Serial.println("Stop: Bewegung stoppen");
    Serial.println("Go: Motor aktivieren");
    Serial.println("status: Status anzeigen");
    Serial.println("Zahl: Position anfahren");
    Serial.println("==============");
  }
  else {
    // Versuche als Zahl zu interpretieren (Positionsbefehl)
    long position = command.toInt();
    
    if (position != 0 || command == "0") {
      // Berechne die Richtung anhand der Differenz
      long delta = position - currentPosition;
      motorDirection = (delta > 0) ? HIGH : LOW;
      digitalWrite(DIR_PIN, motorDirection);
      
      targetPosition = position;
      movingToPosition = true;
      
      Serial.print("DEBUG: Zielposition: ");
      Serial.print(targetPosition);
      Serial.print(" | Delta: ");
      Serial.println(delta);
    } else {
      Serial.println("DEBUG: Ungültige Eingabe");
      motorEnabled = false;
      digitalWrite(ENA_PIN, HIGH);
      movingToPosition = false;
      Serial.println(CODE4);
    }
  }
}

void moveToPosition() {
  if (currentPosition != targetPosition) {
    if (micros() - lastStepTime >= pulseDelay) {
      stepState = !stepState;
      digitalWrite(STEP_PIN, stepState);
      
      if (stepState == LOW) {
        // Positionsupdate mit Richtungsüberprüfung
        if (motorDirection == HIGH) {
          currentPosition++;
        } else {
          currentPosition--;
        }
        stepCount++;
      }
      lastStepTime = micros();
    }
  } else {
    movingToPosition = false;
    Serial.println(CODE1);  // Bestätigung senden
  }
}

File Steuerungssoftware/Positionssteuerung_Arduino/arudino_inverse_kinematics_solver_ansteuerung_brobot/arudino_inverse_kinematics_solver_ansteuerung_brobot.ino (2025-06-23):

// TB6600 Multi-Joint Stepper Control für TCP Steuerung
const int JOINT1_PINS[3] = {8, 9, 10};   // STEP, DIR, ENA für Joint 1 (Base)
const int JOINT2_PINS[3] = {11, 12, 13}; // STEP, DIR, ENA für Joint 2 (Shoulder)
const int JOINT3_PINS[3] = {5, 6, 7};    // STEP, DIR, ENA für Joint 3 (Elbow)
const int JOINT4_PINS[3] = {2, 3, 4};    // STEP, DIR, ENA für Joint 4 (Wrist)

// Motor-Parameter für jeden Joint
struct JointMotor {
  int stepPin;
  int dirPin;
  int enaPin;
  long targetPosition;
  long currentPosition;
  bool moving;
  bool direction;
  unsigned long lastStepTime;
  double pulseDelay;
  bool stepState;
};

// Joint-Motoren initialisieren
JointMotor joints[4] = {
  {8, 9, 10, 0, 0, false, false, 0, 400, false},   // Joint 1
  {11, 12, 13, 0, 0, false, false, 0, 400, false}, // Joint 2
  {5, 6, 7, 0, 0, false, false, 0, 400, false},    // Joint 3
  {2, 3, 4, 0, 0, false, false, 0, 400, false}     // Joint 4
};

// Globale Parameter
double globalSpeed = 400;  // Standard Geschwindigkeit in µs
String receivedCommand = "";
boolean commandComplete = false;
boolean allMotorsEnabled = true;
int activeMotors = 0;

// Status-Codes
const String CODE1 = "Code1: Position wurde angefahren";
const String CODE2 = "Code2: Vorgang wurde abgebrochen";
const String CODE3 = "Code3: Motor ist einsatzbereit!";
const String CODE4 = "Code4: Fehlerhafte Eingabe. Motor wurde abgeschaltet";

void setup() {
  Serial.begin(9600);
  
  // Initialisiere alle Joint-Pins
  for(int i = 0; i < 4; i++) {
    pinMode(joints[i].stepPin, OUTPUT);
    pinMode(joints[i].dirPin, OUTPUT);
    pinMode(joints[i].enaPin, OUTPUT);
    
    // Motoren aktivieren (LOW = aktiv)
    digitalWrite(joints[i].enaPin, LOW);
    digitalWrite(joints[i].dirPin, LOW);
    digitalWrite(joints[i].stepPin, LOW);
    
    joints[i].pulseDelay = globalSpeed;
  }
  
  Serial.println("DEBUG: 4-Joint TCP Control bereit");
  Serial.println(CODE3);
  printStatus();
}

void loop() {
  // Serielle Kommunikation verarbeiten
  if (Serial.available() > 0) {
    char inChar = (char)Serial.read();
    
    if (inChar == '\n' || inChar == '\r') {
      if (receivedCommand.length() > 0) {
        commandComplete = true;
      }
    } else {
      receivedCommand += inChar;
    }
  }
  
  // Befehl verarbeiten
  if (commandComplete) {
    processCommand(receivedCommand);
    receivedCommand = "";
    commandComplete = false;
  }
  
  // Alle Motoren bewegen
  moveAllMotors();
  
  // Prüfe ob alle Motoren ihre Ziele erreicht haben
  checkMovementComplete();
}

void processCommand(String command) {
  command.trim();
  
  Serial.print("DEBUG: Befehl empfangen: '");
  Serial.print(command);
  Serial.println("'");
  
  if (command.equalsIgnoreCase("STOP")) {
    Serial.println("DEBUG: STOP - Alle Motoren stoppen");
    stopAllMotors();
    Serial.println(CODE2);
  }
  else if (command.equalsIgnoreCase("GO")) {
    Serial.println("DEBUG: GO - Alle Motoren aktivieren");
    enableAllMotors();
    Serial.println(CODE3);
  }
  else if (command.equalsIgnoreCase("status")) {
    printStatus();
  }
  else if (command.startsWith("SPEED:")) {
    // Globale Geschwindigkeit setzen: SPEED:300
    double newSpeed = command.substring(6).toDouble();
    if (newSpeed >= 100 && newSpeed <= 2000) {
      globalSpeed = newSpeed;
      for(int i = 0; i < 4; i++) {
        joints[i].pulseDelay = globalSpeed;
      }
      Serial.print("Geschwindigkeit gesetzt auf ");
      Serial.print(globalSpeed);
      Serial.println("µs");
    } else {
      Serial.println("Ungültige Geschwindigkeit (100-2000µs)");
    }
  }
  else if (command.startsWith("J") && command.indexOf(":") > 0) {
    // Joint-Befehl: J1:1000, J2:-500, etc.
    int colonPos = command.indexOf(":");
    int jointNum = command.substring(1, colonPos).toInt();
    long targetSteps = command.substring(colonPos + 1).toInt();
    
    if (jointNum >= 1 && jointNum <= 4) {
      setJointTarget(jointNum - 1, targetSteps);  // Array ist 0-basiert
    } else {
      Serial.println("Ungültige Joint-Nummer (1-4)");
      Serial.println(CODE4);
    }
  }
  else if (command.startsWith("MULTI:")) {
    // Multi-Joint Befehl: MULTI:J1:1000,J2:-500,J3:200,J4:0
    parseMultiJointCommand(command.substring(6));
  }
  else {
    Serial.println("DEBUG: Unbekannter Befehl");
    Serial.println(CODE4);
  }
}

void parseMultiJointCommand(String jointCommands) {
  Serial.println("DEBUG: Multi-Joint Befehl wird verarbeitet");
  
  // Teile die Befehle bei Kommas
  int startPos = 0;
  int commaPos = 0;
  
  while (commaPos >= 0) {
    commaPos = jointCommands.indexOf(',', startPos);
    String singleCommand;
    
    if (commaPos >= 0) {
      singleCommand = jointCommands.substring(startPos, commaPos);
      startPos = commaPos + 1;
    } else {
      singleCommand = jointCommands.substring(startPos);
    }
    
    singleCommand.trim();
    
    // Verarbeite einzelnen Joint-Befehl
    if (singleCommand.startsWith("J") && singleCommand.indexOf(":") > 0) {
      int colonPos = singleCommand.indexOf(":");
      int jointNum = singleCommand.substring(1, colonPos).toInt();
      long targetSteps = singleCommand.substring(colonPos + 1).toInt();
      
      if (jointNum >= 1 && jointNum <= 4) {
        setJointTarget(jointNum - 1, targetSteps);
      }
    }
  }
}

void setJointTarget(int jointIndex, long targetSteps) {
  if (jointIndex < 0 || jointIndex >= 4) return;
  
  joints[jointIndex].targetPosition = targetSteps;
  
  // Berechne Richtung
  long delta = targetSteps - joints[jointIndex].currentPosition;
  joints[jointIndex].direction = (delta > 0);
  digitalWrite(joints[jointIndex].dirPin, joints[jointIndex].direction ? HIGH : LOW);
  
  // Starte Bewegung wenn Unterschied vorhanden
  if (delta != 0) {
    joints[jointIndex].moving = true;
    activeMotors++;
  }
  
  Serial.print("Joint ");
  Serial.print(jointIndex + 1);
  Serial.print(" Ziel: ");
  Serial.print(targetSteps);
  Serial.print(" (Delta: ");
  Serial.print(delta);
  Serial.println(")");
}

void moveAllMotors() {
  for (int i = 0; i < 4; i++) {
    if (joints[i].moving && allMotorsEnabled) {
      moveJoint(i);
    }
  }
}

void moveJoint(int jointIndex) {
  if (jointIndex < 0 || jointIndex >= 4) return;
  
  JointMotor* joint = &joints[jointIndex];
  
  if (joint->currentPosition != joint->targetPosition) {
    if (micros() - joint->lastStepTime >= joint->pulseDelay) {
      joint->stepState = !joint->stepState;
      digitalWrite(joint->stepPin, joint->stepState);
      
      if (joint->stepState == LOW) {
        // Position aktualisieren
        if (joint->direction) {
          joint->currentPosition++;
        } else {
          joint->currentPosition--;
        }
      }
      joint->lastStepTime = micros();
    }
  } else {
    // Ziel erreicht
    if (joint->moving) {
      joint->moving = false;
      activeMotors--;
      Serial.print("Joint ");
      Serial.print(jointIndex + 1);
      Serial.println(" Ziel erreicht");
    }
  }
}
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

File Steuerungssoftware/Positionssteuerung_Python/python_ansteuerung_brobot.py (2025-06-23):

import serial
import time
import threading
import queue

# Fehlercodes - synchronisiert mit Arduino
Fehlercode1 = "Code1: Position wurde angefahren"
Fehlercode2 = "Code2: Vorgang wurde abgebrochen"
Fehlercode3 = "Code3: Motor ist einsatzbereit!"
Fehlercode4 = "Code4: Fehlerhafte Eingabe. Motor wurde abgeschaltet"

# Message Queue für Thread-sichere Kommunikation
message_queue = queue.Queue()
running = True

# Serielle Verbindungsparameter
arduino_port = 'COM3'  # Passe den Port an
baud_rate = 9600

# Verbindung zur seriellen Schnittstelle herstellen
ser = serial.Serial(arduino_port, baud_rate, timeout=1)
time.sleep(2)  # Arduino Zeit zum Initialisieren geben

def send_data(data):
    """Daten an Arduino senden."""
    ser.flushInput()   # Eingangspuffer leeren
    ser.flushOutput()  # Ausgangspuffer leeren
    ser.write((str(data) + '\n').encode())
    print(f"→ Befehl gesendet: {data}")

def read_data():
    """Daten vom Arduino empfangen."""
    if ser.in_waiting > 0:
        received_data = ser.readline().decode().strip()
        return received_data
    return None

def continuous_read():
    """Kontinuierliches Lesen von Arduino-Nachrichten."""
    global running
    while running:
        try:
            message = read_data()
            if message:
                message_queue.put(message)
            time.sleep(0.01)
        except Exception as e:
            print(f"Fehler beim Lesen: {e}")
            break

def clear_buffers():
    """Alle seriellen Puffer leeren."""
    ser.flushInput()
    ser.flushOutput()
    time.sleep(0.1)
    while ser.in_waiting > 0:
        ser.read()
    # Queue auch leeren
    while not message_queue.empty():
        try:
            message_queue.get_nowait()
        except queue.Empty:
            break
    #print("Puffer geleert")

def main():
    """Hauptprogramm - Einfache Positionssteuerung."""
    print("=" * 50)
    print("• Position         → Fahre zu Position")
    print("• Stop             → Bewegung stoppen") 
    print("• Go               → Motor aktivieren")
    print("=" * 50)
    
    # Puffer initial leeren
    clear_buffers()
    
    while True:
        try:
            user_input = input("\nPosition eingeben: ").strip()
            
            if user_input.lower() == 'exit':
                print("Programm wird beendet...")
                break
            elif user_input.lower() == 'clear':
                clear_buffers()
                continue
            
            # Befehl senden
            send_data(user_input)
            
            # Auf Antwort warten
            print("Warte auf Arduino-Antwort...")
            timeout_start = time.time()
            response_received = False
            
            while not response_received and (time.time() - timeout_start) < 15:
                try:
                    message = message_queue.get(timeout=0.5)
                    
                    # Prüfe auf spezielle Fehlercodes
                    if message == Fehlercode1:
                        print(f" {message}")
                        response_received = True
                    elif message == Fehlercode2:
                        print(f" {message}")
                        response_received = True
                    elif message == Fehlercode3:
                        print(f" {message}")
                        response_received = True
                    elif message == Fehlercode4:
                        print(f" {message}")
                        print("Motor mit 'Go' aktivieren!")
                        response_received = True
                    else:
                        # Normale Arduino-Nachricht
                        print(f" Arduino: {message}")
                        # Bei normalen Nachrichten nicht als "response_received" markieren
                        # außer es ist offensichtlich eine Bestätigung
                        if any(keyword in message.lower() for keyword in ['gesetzt', 'geändert', 'aktiviert', 'deaktiviert', 'durchgeführt']):
                            response_received = True
                
                except queue.Empty:
                    # Kein Timeout-Fehler, einfach weiter warten
                    continue
            
            if not response_received:
                print(" Timeout - Arduino antwortet nicht!")
                print(" Versuche 'clear' oder 'Stop'")
    
        except KeyboardInterrupt:
            print("\n Programm unterbrochen!")
            send_data("Stop")
            break
        except Exception as e:
            print(f" Fehler: {e}")

# Programm starten
try:
    # Starte kontinuierliches Lesen in separatem Thread
    read_thread = threading.Thread(target=continuous_read, daemon=True)
    read_thread.start()
    
    # Hauptprogramm starten
    main()
    
except KeyboardInterrupt:
    print("\n Programm wird beendet...")
    send_data("Stop")
finally:
    running = False
    ser.close()
    print("Verbindung geschlossen")

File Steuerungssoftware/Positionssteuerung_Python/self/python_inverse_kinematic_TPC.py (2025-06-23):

import serial
import time
import math


def send_data(data):
    ser.write((str(data) + '\n').encode())

def read_data():
    received_data = ser.readline().decode().strip()
    return received_data

def print_from_py(x):
    print("Python-> " +x)

def print_from_ardu(x):
    print("Arduino-> "+x)

def inverse_kinematik(old_x, old_y, old_thetta, new_x, new_y, new_thetta):
    print_from_py("Starte berechnung der Inversen Kinematik")

    l1=154      #mm
    l2=368
    l3=289
    l4=260

    x_1=0
    y_1=0
    x_2=0
    y_2=l1

    #Berechnung TCP zu Joint 4 (OLD)
    x_tcp_old=old_x
    y_tcp_old=old_y

    x_4_old=x_tcp_old-math.sin(math.radians(old_thetta))*l4
    y_4_old=y_tcp_old+math.cos(math.radians(old_thetta))*l4

    #x_4_old=old_x
    #y_4_old=old_y

    #Berechnung Joint4 zu Joint 2 (OLD)
    l24_old=math.sqrt(math.pow((x_4_old-x_2),2)+math.pow((y_4_old-y_2),2))
    alpha_groß_old=math.atan2(x_4_old,(y_4_old-y_2))         #für acos eher atan2 nehmen, dann auch negative werte
    alpha_old=math.acos(((-1)*math.pow(l3,2)+math.pow(l2,2)+math.pow(l24_old,2))/(2*l2*l24_old))
    alpha_2_old=alpha_groß_old-alpha_old

    y_3_old=y_2+math.cos(alpha_2_old)*l2
    x_3_old=x_2+math.sin(180-90-alpha_2_old)*l2

    beta_old=math.acos(((-1)*math.pow(l24_old,2)+math.pow(l3,2)+math.pow(l2,2))/(2*l3*l2))
    gamma_old=math.acos(((-1)*math.pow(l2,2)+math.pow(l3,2)+math.pow(l24_old,2))/(2*l3*l24_old))

    #epsilon_old=math.atan2(x_4_old,y_4_old)
    epsilon_old=math.asin(x_4_old/l24_old)

    thetta_gamma_old=(math.pi/2)-epsilon_old-gamma_old

    thetta_epsilon_old=math.radians(old_thetta)+epsilon_old+gamma_old

    if(x_4_old<x_1):
        epsilon_old=math.pi-epsilon_old

    #Berechnung TCP zu Joint 4 (OLD)
    x_tcp_new=new_x
    y_tcp_new=new_y

    x_4_new=x_tcp_new-math.sin(math.radians(new_thetta))*l4
    y_4_new=y_tcp_new+math.cos(math.radians(new_thetta))*l4

    #x_4_new=new_x
    #y_4_new=new_y

    #Berechnung Joint4 zu Joint 2
    l24_new=math.sqrt(math.pow((x_4_new-x_2),2)+math.pow((y_4_new-y_2),2))
    alpha_groß_new=math.atan2(x_4_new,(y_4_new-y_2))
    alpha_new=math.acos(((-1)*math.pow(l3,2)+math.pow(l2,2)+math.pow(l24_new,2))/(2*l2*l24_new))
    alpha_2_new=alpha_groß_new-alpha_new

    y_3_new=y_2+math.cos(alpha_2_new)*l2
    x_3_new=x_2+math.sin(180-90-alpha_2_new)*l2

    beta_new=math.acos(((-1)*math.pow(l24_new,2)+math.pow(l3,2)+math.pow(l2,2))/(2*l3*l2))
    gamma_new=math.acos(((-1)*math.pow(l2,2)+math.pow(l3,2)+math.pow(l24_new,2))/(2*l3*l24_new))

    #epsilon_new=math.atan2(x_4_new,y_4_new)
    epsilon_new=math.asin(x_4_new/l24_new)
    
    if(x_4_new<x_1):
        epsilon_new=math.pi-epsilon_new

    

    thetta_gamma_new=(math.pi/2)-epsilon_new-gamma_new

    thetta_epsilon_new=math.radians(new_thetta)+epsilon_new+gamma_new

    #Berechnung der Differenz
    delta_alpha=alpha_2_old-alpha_2_new     #weil Winkel nicht im Dreieck sondern auserhalb (daher old-new)
    delta_beta=beta_new-beta_old

    delta_epsilon_thetta=thetta_epsilon_new-thetta_epsilon_old

    #delta_thetta_2=math.radians(new_thetta)-math.radians(old_thetta)
    delta_thetta_gamma=math.radians(thetta_gamma_old)-math.radians(thetta_gamma_new)
    

    #joint 2: 32800 Stepps für 360°
    alpha_stepps=(32800/(2*math.pi))*(delta_alpha)        #stepps die der motor jetzt machen muss, um auf die Position zu fahren

    #joint 3:25200 Stepps für 360°
    beta_stepps=(25200/(2*math.pi))*(delta_beta)

    #joint 4: 13000 Stepps für 360°
    thetta_stepps=(13000/(2*math.pi))*(delta_epsilon_thetta)
    #thetta_stepps=(13000/(2*math.pi))*(delta_thetta_gamma)

    print_from_py("Berechnung beendet, alpha um "+str(math.degrees(delta_alpha)) +"° verfahren und beta um "+str(math.degrees(delta_beta)) +"° verfahren und epsilon "+str(math.degrees(delta_epsilon_thetta)) +"° verfahren!")
    return alpha_stepps, beta_stepps, thetta_stepps

    #Hier jetzt noch relative Bewegung zur alten tcp_x und tcp_y berechnen
    #Programmieren, dass:
    # 1. Bei der Initialisierung die X und Y Koordinaten der Aktuellen Position eingegeben werden müssen
    # 2. alte Position gespeichert wird
    # 3. Die Neue Position anhand der Alten angefahren wird
    # 4. Messen, wie Viele schritte pro Gelenk eine Umdrehung sind 
    #       [Joint 1 (rotation): 5500Stepps := 90°]" [Joint 2: 8200Stepps := 90°]" Joint 3:[6300Stepps := 90°]" Joint 4:[3250Stepps := 90°]"
    #  5. Arduino gleichzeiteige Bewegung: alle Stepps gleich schnell, nur Schritte der Motoren übergeben (Taktung gleich bzw in
    #  einer Funktion!)


    #   6. Berechnen TCP zu Joint4 : 
    #   7. Quadrantenprüfung (wann + und wann -) zu joint 4 und TCP
    #   8. programmieren dass alle gleichzeitig fahren
    #   9. eventuell threatten (skripte gleichzeitig ablaufen lassen)

    #Differenz der aktuellen


   

    

    print_from_py("Inverse Kinematik berechnet")


# Serielle Verbindungsparameter
arduino_port = 'COM3'  # Portangabe Windows
#arduino_port = '/dev/ttyUSB0'  # Portangabe Linux
baud_rate = 9600

# Verbindung zur seriellen Schnittstelle herstellen
ser = serial.Serial(arduino_port, baud_rate, timeout=5)
time.sleep(2)  # Arduino Zeit zum Initialisieren geben

#main
print('----Brobot-Controll----\n Modus Wählen (automatic "a" or manuell "m") ')
inputdata=input()
send_data(inputdata)

data=""
stepindex=0
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

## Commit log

2025-06-23 Innitial commit
    [17HS19-2004S1.STEP, Abrollrad.SLDPRT, Abrollscheibe.SLDPRT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]
2026-02-06 All relevant files for the project
    [Abrollrad.SLDPRT, Abrollrad.STL, Base-Halterungen_Aufrecht.SLDPRT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]
2026-02-06 added gripper files
2026-02-06 Add README for BroBot project
    Added comprehensive README for BroBot project, detailing features, hardware, software, installation, usage, kinematics, troubleshooting, and contributions.
2026-02-06 Update image path for BroBot prototype in README
2026-02-06 Fix image path in README.md
    Updated image path for the BroBot prototype.
2026-02-06 Fix image path in README.md
    Updated image path for BroBot prototype in README.
2026-02-06 Add gripper image to Working Position section
    Added an image of the gripper in the Working Position section.
